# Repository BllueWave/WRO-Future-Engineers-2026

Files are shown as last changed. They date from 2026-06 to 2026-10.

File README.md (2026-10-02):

<p align="center">
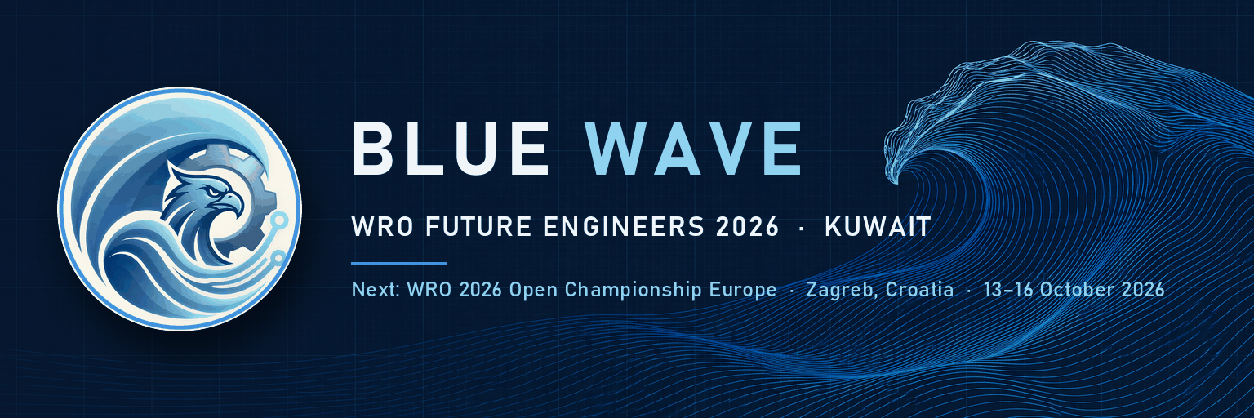
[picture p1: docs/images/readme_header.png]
BLUE WAVE, WRO Future Engineers 2026, Kuwait
  
</p>

<h1 align="center">BLUE WAVE</h1>

<p align="center"><b>WRO Future Engineers 2026 · Kuwait</b><br>Kuwait national round: 1st place, 61 points<br>Next: WRO 2026 Open Championship Europe, Zagreb, Croatia, 13–16 October 2026</p>

<p align="center">
  
  
  
  
  
</p>

Our car is a WLtoys 1:28 four-wheel-drive chassis (one brushed motor, propshaft, front and rear differentials, Ackermann steering) carrying a Raspberry Pi 5, a Hiwonder RRC Lite controller board, an LDROBOT LD19 lidar, an Angstrong HP60C camera and a Cytron MD13S motor driver, inside a body we designed and printed in PETG (BW-2). The car has no wheel encoder. It finds its position from the lidar, which scans 50 mm above the mat so that it sees the 100 mm field walls and the traffic signs, and from the IMU. The camera only tells red from green and finds the magenta parking limitations. All planning and control run in Python on the Pi 5.

Every number on these pages comes from a run log of the car, a calibration file or the CAD model, and the pages say which. **MAT** = measured on the car on our practice mat. **CAD** = read from the body model, not yet measured on the car. **SIM** = our simulator, which is calibrated to the mat but is not the judge.

## Results

| Event or run | Result | Source |
|---|---|---|
| WRO Future Engineers 2026, Kuwait national round, June 2026 | **1st place, 61 points**, won with our first car (Arduino Uno), which stays in the history at tag [`v1.0-june-2026`](https://github.com/BllueWave/WRO-Future-Engineers-2026/tree/v1.0-june-2026) | competition result |
| Open Challenge, practice mat, 2026-10-01 (MAT) | **14.7 s** for 3 laps, 12 of 12 corners driven without stopping, stop inside the start section, no contact, counter-clockwise, pack 8.05 V | run `20261001-161301.412-open_v7`, program `BEST_OPEN_14s` |
| Obstacle Challenge, practice mat, 2026-10-01 (MAT) | **55.8 s**: start in the parking lot, 3 laps with all 6 signs passed on the correct side in every lap, parallel park with all 4 corners inside the lot, counter-clockwise, pack 8.25 V | run `20261001-222840.106-obs_v17`, program `obs_v17` |

All corridors on that mat were 1000 mm wide. Both runs are counter-clockwise; the clockwise runs of these two programs are SIM so far. The full list of mat runs, with the pack voltage of each, is in [Build, test and reproduce](docs/05-build-test-reproduce.md#results-on-the-mat).

## Contents

| Appendix C criterion | Page | What it covers |
|---|---|---|
| 1. Mobility | [Mobility and mechanical design](docs/01-mobility.md) | Why this chassis, size and parking-lot length, drive train and the fitted speed model, braking, steering trim and the unequal steering lock, understeer against speed, the BW-2 body |
| 2. Power and sensors | [Power and sensor architecture](docs/02-power-and-sensors.md) | Power tree and budget, pin map, why a 50 mm lidar plane, camera field of view and pitch, IMU, speed without an encoder, calibration, failure handling |
| 3. Software and obstacle strategy | [Software architecture and obstacle strategy](docs/03-software-and-strategy.md) | Where each module runs, race mode, the Open racing line, the Obstacle pose, sign map and path, the lot exit and the parallel park, constants and their sources |
| 4. Systems thinking and decisions | [Systems thinking and engineering decisions](docs/04-engineering-decisions.md) | Constraints, decision log, the measured lessons (steering trim, battery compensation, the Q stop, the camera's field of view), version history, risks |
| 5. Reproducibility | [Build, test and reproduce](docs/05-build-test-reproduce.md) | Parts list, printed parts, software set-up, race mode, bench check, test method, mat and SIM results, how to repeat each number |

Other folders: [vehicle photos](Vehicle_Photos/README.md) · [wiring](Schemes/README.md) · [3D models](Models/README.md) · [videos](videos/README.md) · [source code](src/README.md) · [test sheet](docs/test-sheet.md)

Scoring reference: section 7 and Appendix C of the [2026 Future Engineers rules](https://wro-association.org/wp-content/uploads/WRO-2026-Future-Engineers-Self-Driving-Cars-General-Rules.pdf).

## The car

<p align="center">
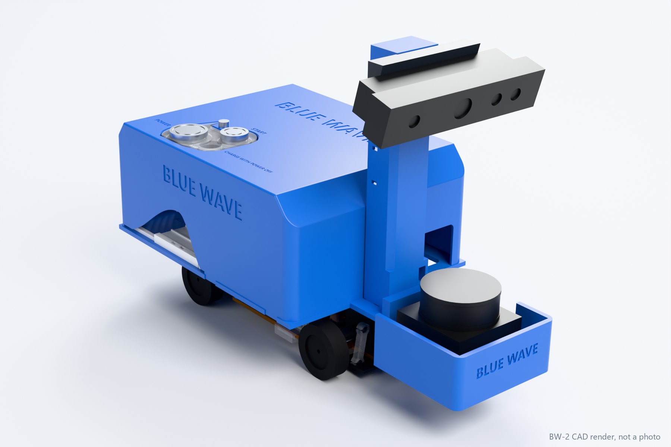
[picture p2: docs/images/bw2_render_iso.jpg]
CAD render of the BW-2 body on the WLtoys chassis: blue shell and tower, camera on the tower, lidar bay at the front
  
  <br><sub>CAD render of the BW-2 model, not a photo. Photos of the car: <a href="Vehicle_Photos/README.md">Vehicle_Photos</a>.</sub>
</p>

| Item | Value | Tag |
|---|---|---|
| Size | 224.8 × 111.0 × 157.2 mm (rule 11.1 limit 300 × 200 × 300 mm) | CAD |
| Mass | 721–737 g estimated from the CAD solids and the part list; this model still includes three printed parts that are not on the car, so the car is lighter; not yet weighed (rule 11.2 limit 1.5 kg) | CAD |
| Chassis | WLtoys 1:28, model 284131: one 130-size brushed motor, propshaft, front and rear differentials, Ackermann front axle; wheelbase 98.0 mm, track 64.24 mm, wheel 27.0 mm | CAD |
| Computer | Raspberry Pi 5 with Active Cooler: perception, planning, control | |
| Controller board | Hiwonder RRC Lite (STM32F407), stock firmware: steering servo pulses, 6-axis IMU at 50 Hz, buzzer, keys; powers the Pi over USB-C | MAT (IMU rate) |
| Drive | Cytron MD13S on Pi GPIO12 (PWM, 490 Hz) and GPIO16 (direction); PWM low = brake | MAT |
| Speed | v = 5.276 m/s × (duty − 0.1012), fitted on 1599 lidar speed samples, rms error 0.075 m/s; 1.39 m/s top speed seen in the 14.7 s run | MAT |
| Steering | stock micro servo on RRC PWM port 3; 30° left and 22° right at the wheels; full-lock left radius 237 mm at 0.2 m/s | MAT |
| Lidar | LDROBOT LD19, 360°, about 10 Hz, scan plane 50 mm above the mat (walls are 100 mm) | CAD (height), MAT (rate) |
| Camera | Angstrong HP60C RGB-D, colour 640 × 480 at 14 frames/s, ±29.3° horizontal field of view, pitch 19.61° down | MAT |
| Power | 7.4 V 2200 mAh pack (2 × 18650), one 16 mm latching power switch | |
| Start | one 12 mm start button on GPIO17 (rules 9.10 and 9.11) | |

<p align="center">
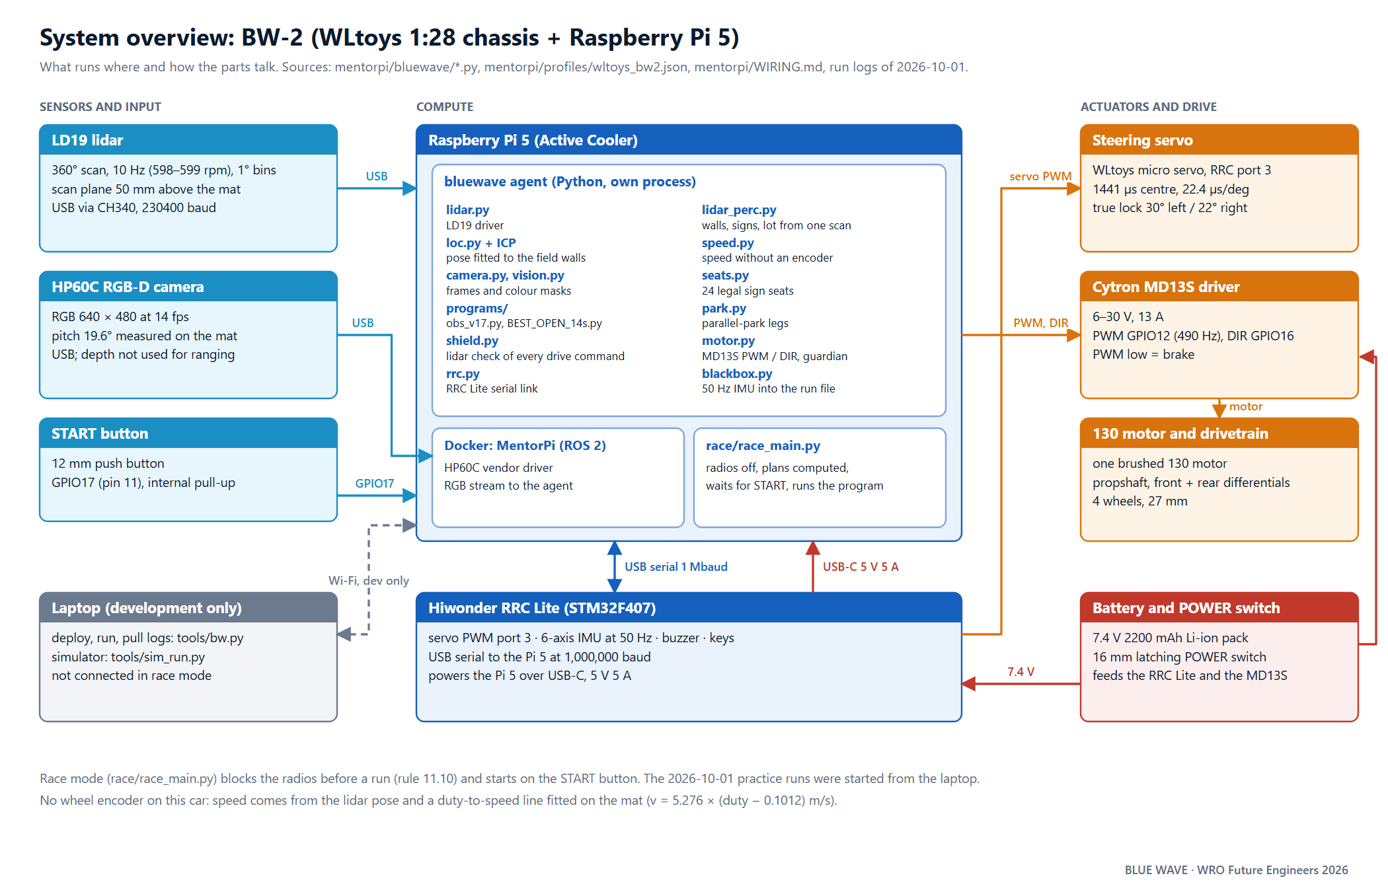
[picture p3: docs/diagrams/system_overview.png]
System overview: the pack feeds the RRC Lite and the MD13S through the power switch; the RRC Lite powers the Raspberry Pi 5 over USB-C and talks to it over USB serial; the LD19 lidar and the HP60C camera are on the Pi's USB ports; the Pi drives the MD13S from GPIO12 and GPIO16; the RRC Lite drives 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
  
</p>

### Why these parts

| Part | Why |
|---|---|
| WLtoys chassis | One drive motor through mechanical differentials and one steering servo, as rules 11.3, 11.5 and 11.13 ask. The robot kit we took the electronics from drives each rear wheel with its own motor, which those rules do not allow. |
| LD19 lidar at 50 mm | On the kit's own mount the lidar scanned above the 100 mm walls and signs and read the room behind the field. At 50 mm every wall and sign within 2.2 m is in the scan, which gives the car an absolute position about ten times a second without an encoder. |
| HP60C colour camera | The lidar finds where a sign stands; the camera only has to say red or green, and where the magenta limitations are. Its depth stream gave no returns from the white mat and over-read a sign at 1.25 m as 1.43 m, so we do not use it for range. |
| Raspberry Pi 5 | Lidar fitting, the colour masks, the path planner and the simulator-compatible robot interface all run in Python at a 40 Hz control loop (p99 loop time 32.0 ms, MAT). |
| Cytron MD13S | The controller board's motor ports close a speed loop on an encoder this car does not have. The MD13S takes plain PWM and direction from the Pi, and PWM low shorts the motor, which brakes at 2.08 m/s² (fit over the mat runs). |

More detail and the trade-offs: [Systems thinking and engineering decisions](docs/04-engineering-decisions.md).

## How it works

### Open Challenge (`BEST_OPEN_14s`)

The lidar scan is rotated by the gyro heading into the corridor frame. From it the car reads the wall ahead, both side walls and the inner corner of the island, which gives the width of the next corridor about 1.3 m before the corner. The driving direction is chosen at the start from the gap at the corner. Every corner is one constant-radius 90° arc from this corridor's lane to the next one's, with the radius as large as a 180 mm clearance to the island allows, and the arc speed √(a·R) with a = 2.6 m/s². Lap 1 measures every corridor; laps 2 and 3 plan each corner from that map before it is in sight. The car brakes to the arc speed with a constant-deceleration plan on a speed observer (the fitted duty line corrected by the lidar), steers each arc with the effective wheelbase measured at that speed, and stops inside the start section after 12 corners. A lidar shield checks every drive command against the walls.

### Obstacle Challenge (`obs_v17`)

```mermaid
flowchart LR
    A["Start in the lot<br>direction from the wall beside the car"] --> B["Lot exit<br>planned legs on the real lock of each side"]
    B --> C["Laps 1 to 3<br>lidar pose, sign seats, lane per sign"]
    C -->|"3 laps done"| D["Ride Q's line<br>stop on the braking distance"]
    D -->|"off Q"| E["Realign: back along the line, in again, creep"]
    E --> D
    D -->|"on Q"| F["Park: the exit plan driven in reverse"]
    F --> G["Check all 4 corners inside the lot"]
```

The pose comes from fitting each lidar scan's wall points to the field walls (outer square, island, the lot's limitations), starting from the gyro and the speed observer. Sign pillars found by the lidar are snapped to the 24 positions the rules allow, and each gets its colour from the camera by bearing. Red is passed on its right, green on its left. A sign the lidar has found but the camera has not read is looked at on purpose: the nose turns toward it, and the program counts pixels where the map projects it into the frame. The path is a lane per sign with planned corner radii, followed by pure pursuit from the rear axle with a swept-footprint guard. After three laps the car rides the line to the point Q where the lot exit ended, stops there, and drives the exit plan in reverse into the lot. The run counts as parked only when all four corners of the car are inside.

Full description, state machines and constants: [Software and strategy](docs/03-software-and-strategy.md).

### Code modules and the parts they use

| Module (in `src/`) | What it does | Parts |
|---|---|---|
| `bluewave/hw.py` | the `Robot` object: one interface on the car and in the simulator | all |
| `bluewave/rrc.py` | serial driver of the RRC Lite (1,000,000 baud): servo pulses, IMU, buzzer, keys | RRC Lite, steering servo, IMU |
| `bluewave/motor.py`, `bluewave/speed.py` | PWM and direction to the MD13S with a stop guardian; speed from the lidar pose and the duty model | MD13S, 130 motor, LD19 |
| `bluewave/lidar.py`, `bluewave/lidar_perc.py` | LD19 driver; walls, pillars and parking limitations from one revolution | LD19 |
| `bluewave/camera.py`, `bluewave/vision.py` | frame grabber and colour masks for red, green and magenta | HP60C |
| `bluewave/field.py`, `bluewave/loc.py` | the field map with the 24 sign seats; localisation | LD19, IMU |
| `bluewave/park.py` | lot exit and parallel park legs on the car's true footprint | all drive parts |
| `bluewave/shield.py` | lidar safety layer that checks every drive command | LD19, MD13S |
| `programs/BEST_OPEN_14s.py` | Open Challenge program | all |
| `programs/obs_v17.py` | Obstacle Challenge program with the parallel park | all |
| `race/race_main.py` | race mode: radios off, READY beeps, waits for the start button, runs the chosen program | start button, buzzer |

## Build and run

1. **Car.** Fit the parts in [Build, test and reproduce](docs/05-build-test-reproduce.md#bill-of-materials) and wire them as in [Schemes](Schemes/README.md). The RRC Lite keeps Hiwonder's firmware; nothing is flashed to it.
2. **Pi 5, once.** On a fresh Raspberry Pi OS Lite (64-bit) card run `src/os/setup_bluewave_os.sh`; it installs `python3-numpy`, `python3-opencv`, `python3-serial` and `python3-lgpio`, the udev rule and the services. On Hiwonder's stock card use `src/os/install_on_stock.sh`, which keeps the vendor container that holds the HP60C driver.
3. **Code.** From the laptop, `py -3 tools/bw.py deploy` (run in `src/`) copies the code to the car. There is nothing to compile: the programs are Python and load at the start of a run.
4. **Calibration file.** `py -3 tools/bw.py body wltoys_bw2` applies the car's numbers from `profiles/wltoys_bw2.json`; the motor and steering fit used by the programs and the simulator is `profiles/plant_mat1001.json`.
5. **Before each round.** Pack at 7.4 V or more, car still: `py -3 tools/bw.py preflight pitch` with one sign 500 mm ahead must answer GO.
6. **Race mode.** Set `race.programs.open=BEST_OPEN_14s`, `race.programs.obstacle=obs_v17` and `race.challenge` for the round, then `py -3 tools/bw.py mode race` and power-cycle the car. At boot every radio is blocked before the race program starts (rule 11.10); two beeps mean READY; the car does not move before the start button.

Step-by-step commands, the bench check and the simulator: [Build, test and reproduce](docs/05-build-test-reproduce.md) and [src/README.md](src/README.md).

## Rules the car must meet

| Rule | Requirement | This car |
|---|---|---|
| 11.1 | at most 300 × 200 × 300 mm | 224.8 × 111.0 × 157.2 mm (CAD); the car keeps one shape at the start, in the lot exit and in the park |
| 11.2 | at most 1.5 kg | 721–737 g (CAD estimate that includes three printed parts not on the car; not yet weighed) |
| 11.3 | four wheels, one driving axle, one steering actuator | one motor through a propshaft and two differentials; one steering servo |
| 11.5, 11.13 | drive motors may not be connected to wheels independently | one drive motor |
| 11.10 | no wireless communication during a round | race mode runs `rfkill block all` before the program starts |
| 9.10 | one power switch | one 16 mm latching switch on the pack's positive lead |
| 9.11 | one start button, the car waits for it | `race_main.py` waits for the one start button before the car moves |

## Repository map

```text
.
├── README.md            this page
├── docs/                criterion pages 01 to 05, test sheet
│   ├── diagrams/        system, wiring, power, sensors, dimensions, run traces
│   ├── images/          header, CAD renders, team cards
│   ├── arena/           3D model of the 2026 field
│   └── team_photos/     work sessions
├── src/                 the code that runs on the Pi 5 (see src/README.md)
├── Models/              printed parts of the BW-2 body (STL)
├── Schemes/             wiring schematic and pin table
├── Vehicle_Photos/      six views of the car
└── videos/              challenge videos
```

| WRO template folder | This repository |
|---|---|
| `t-photos` | `docs/team_photos/` |
| `v-photos` | `Vehicle_Photos/` |
| `video` | `videos/` |
| `schemes` | `Schemes/` |
| `src` | `src/` |
| `models` | `Models/` |
| `other` | `docs/` |

## Team

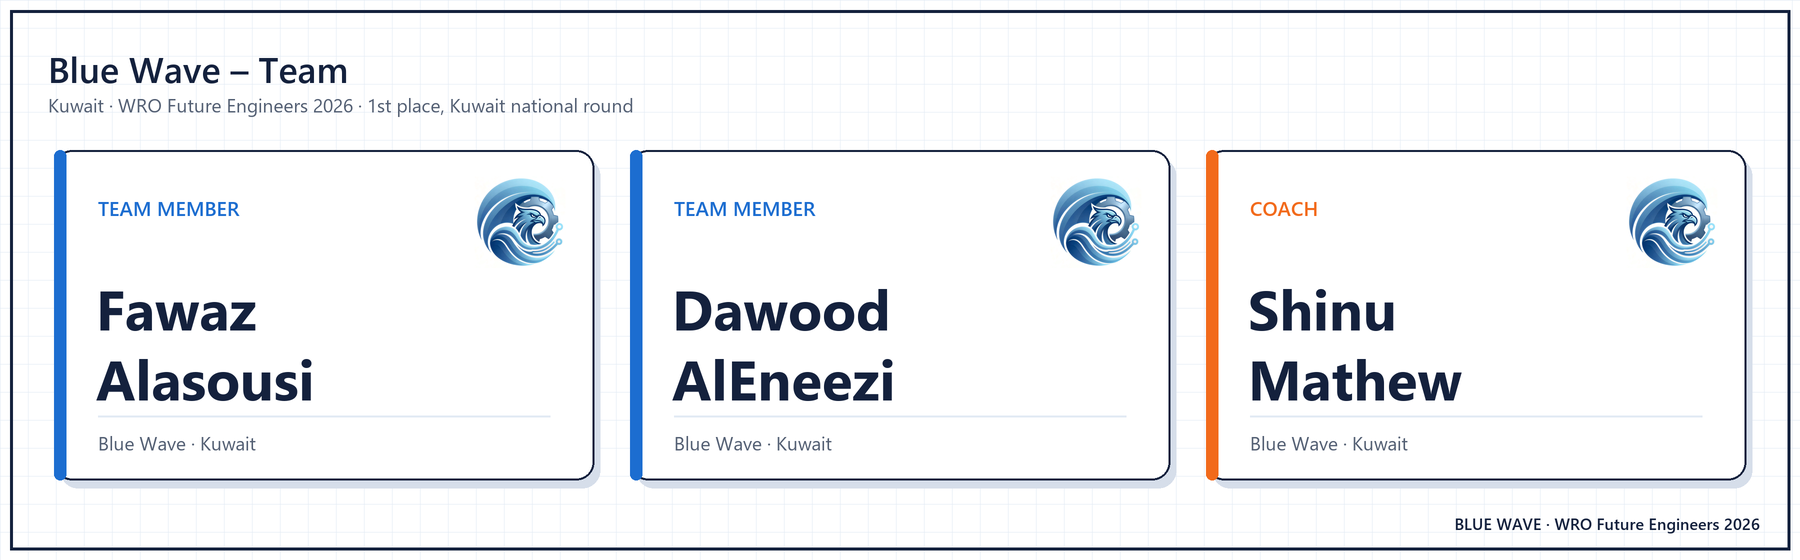
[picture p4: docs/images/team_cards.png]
BLUE WAVE team: Fawaz Alasousi and Dawood AlEneezi, team members; Shinu Mathew, coach


<p align="center">
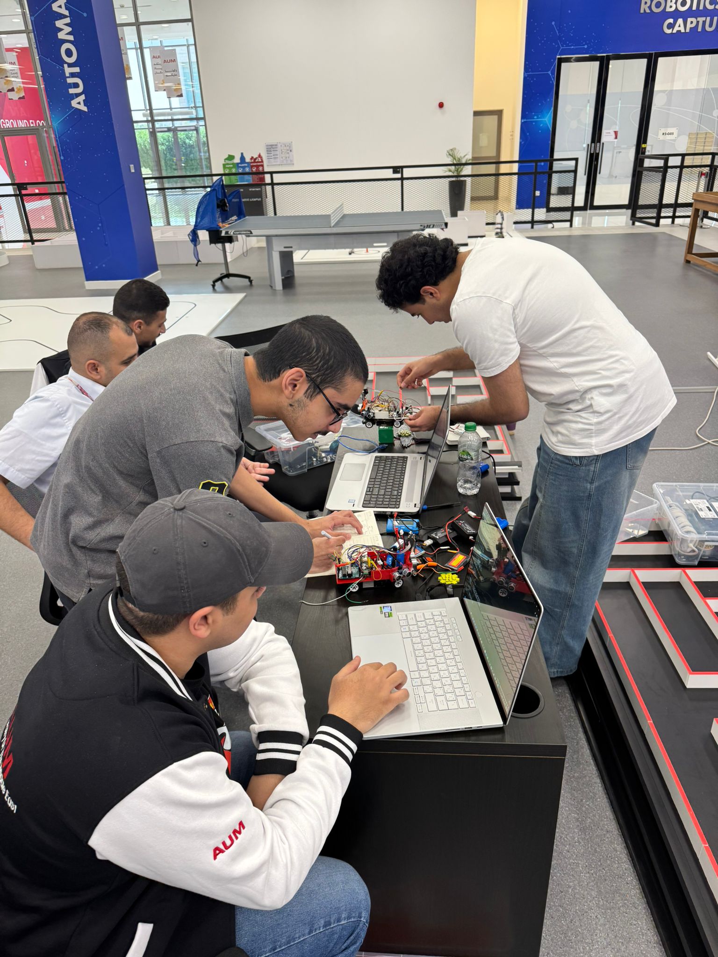
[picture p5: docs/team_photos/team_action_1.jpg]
Work session: the car on the table with laptops
  
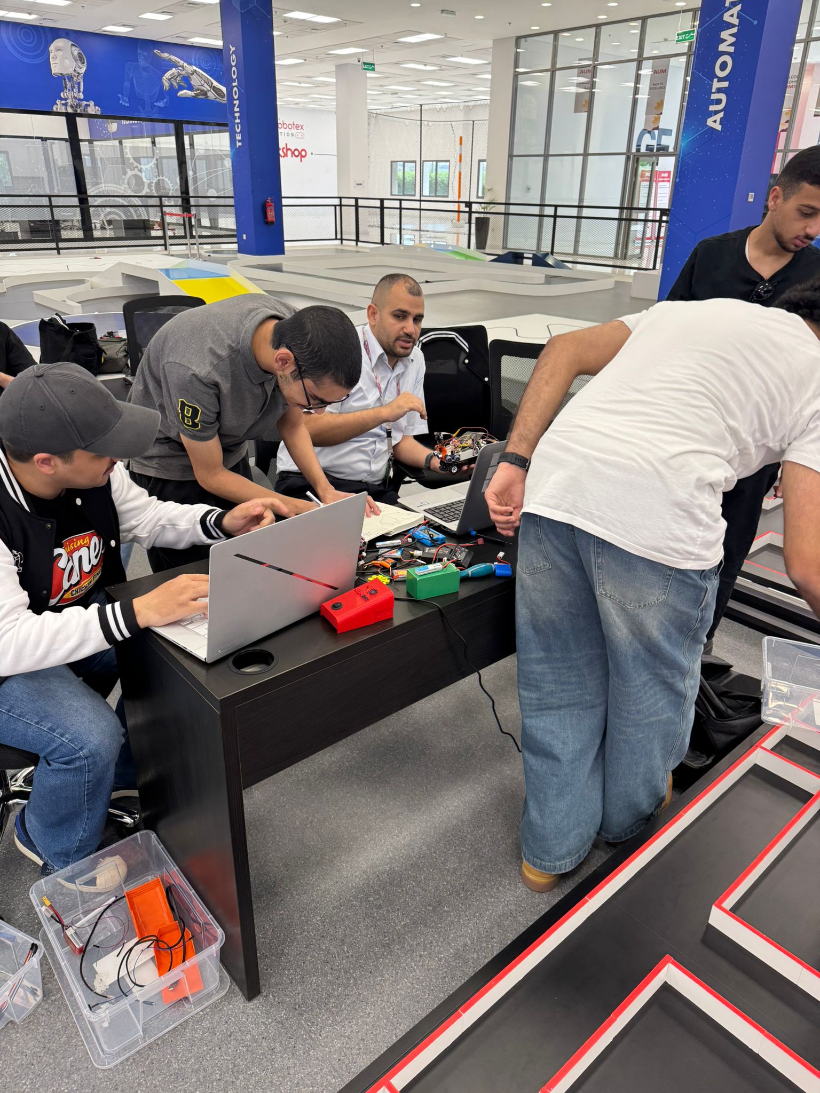
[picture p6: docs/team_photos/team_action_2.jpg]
Work session: testing the car at the field
  
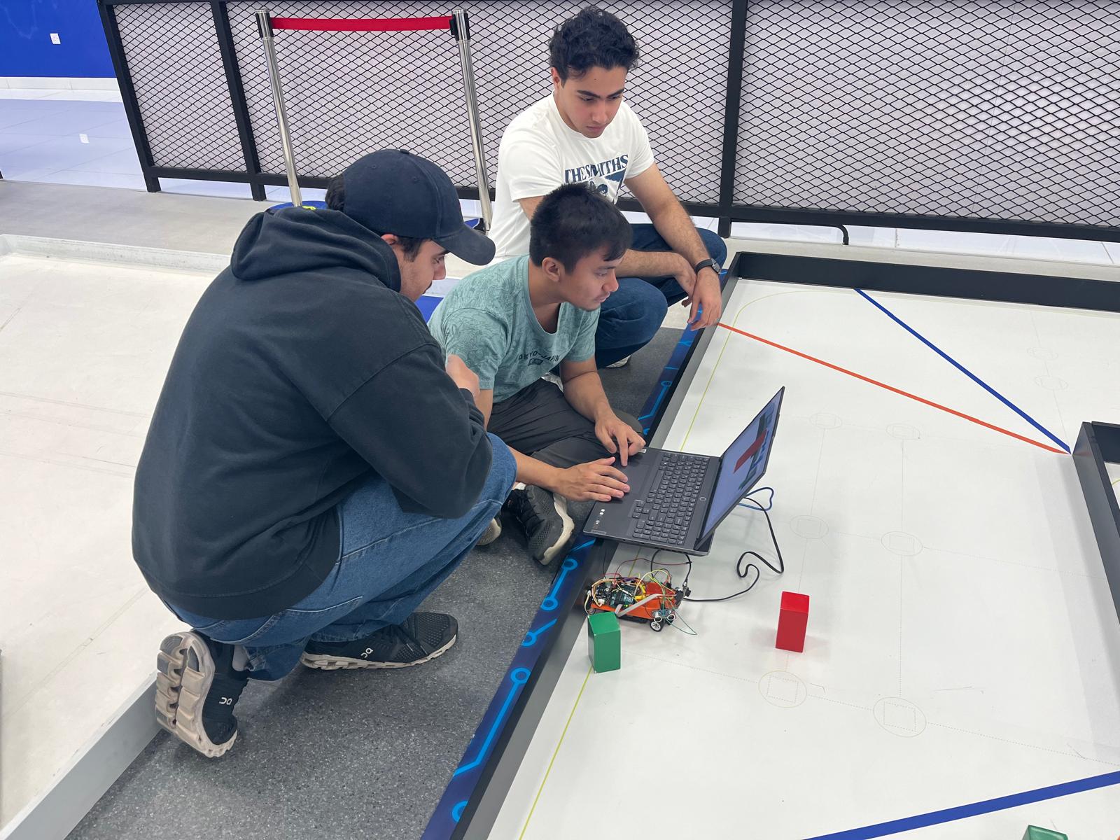
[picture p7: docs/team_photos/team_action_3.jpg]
Work session: tuning the car on the mat
  
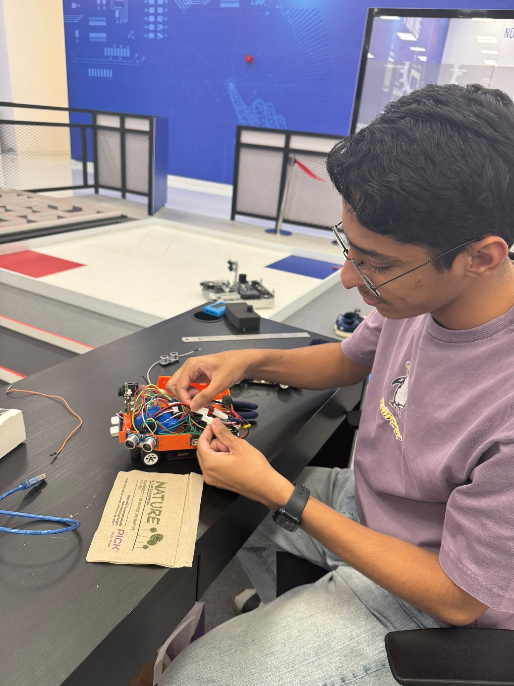
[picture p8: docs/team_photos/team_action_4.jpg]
Work session: wiring the car at the bench
  
</p>

<p align="center"><sub>BLUE WAVE · Kuwait · WRO Future Engineers 2026</sub></p>

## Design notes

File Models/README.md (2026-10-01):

# 3D models: the BW-2 body

The body of our car is BW-2, designed by the team for the WLtoys 1:28 chassis and the MentorPi electronics, and printed
in PETG. Five printed parts are on the car. GitHub shows each STL file in a 3D viewer when you open it.

<p align="center">
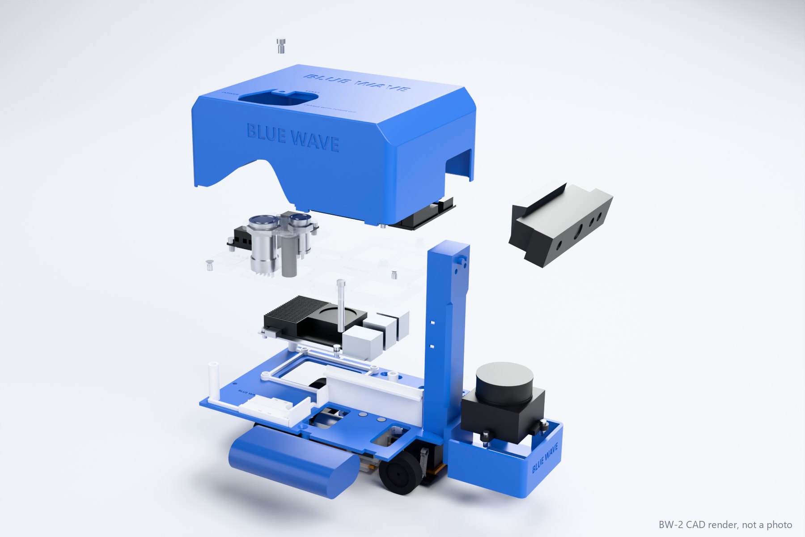
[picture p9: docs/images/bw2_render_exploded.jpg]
Exploded CAD render of the BW-2 body: deck, frame and battery tray, tower with the lidar bay and camera mast, 16 degree camera wedge, shell
  
  <br><sub>CAD render, not a photo.</sub>
</p>

## Printed parts on the car

Material PETG, 0.4 mm nozzle. Print times and masses are slicer estimates. The colour is the one we printed; the file
names keep the colour of the CAD model so that they still match the SHA-256 hashes we recorded for each printed file.

| File | Part | Printed colour | Layer / walls / infill | Supports | Time | Mass |
|---|---|---|---|---|---|---|
| `01_D1_deck_darkgrey.stl` | deck that mounts on the chassis; unchanged from our first body version | blue | | | | 40.9 g |
| `02_L1_frame_battery_tray_darkgrey.stl` | frame and battery tray, with the Pi 5 bosses and the battery bay | white | 0.2 mm / 4 / 40 % | none | 42 min | 14.0 g |
| `04_tower_blue.stl` | tower: camera mast and lidar bay in one print, with 4 lapped datum pads | blue | 0.2 mm / 4 / 40 %, 5 mm brim | enforcer under the foot; blockers in the bores and the cable channel | 115 min | 33.3 g |
| `05_shell_blue.stl` | shell: one print, flat roof, 1.2 mm skin | blue | 0.2 mm / 3 lines of 0.40 mm / 15 % | none | 164 min | 60.6 g |
| `07_cam_wedge_16deg_darkgrey.stl` | camera wedge, 16° | dark grey | 0.12 mm / 5 / 50 % | none | 32 min | 7.9 g |

Total: 157 g of PETG; 353 min of printing for parts 02, 04, 05 and 07.

## What the parts set

| Feature | Value | Set by |
|---|---|---|
| Lidar scan plane | 50.0 mm above the mat, below the top of the 100 mm walls | tower (lidar bay) |
| Lidar position | centre line, 152.0 mm ahead of the rear axle | tower |
| Camera lens | 149.4 mm ahead of the rear axle, 138.28 mm above the mat | tower (mast) |
| Camera pitch | 16° in the model; 19.61° measured on the car | wedge on the mast |
| Overall size | 224.8 × 111.0 × 157.2 mm | whole body |

All values are from the CAD model except the measured pitch. Why these positions: [Mobility](../docs/01-mobility.md#the-bw-2-body)
and [Power and sensors](../docs/02-power-and-sensors.md#sensors).

## Design checks

Run on the full CAD assembly on 2026-09-25 before printing:

| Check | Result |
|---|---|
| Clearance between parts | 91 part pairs, no violation; tightest gap 0.35 mm |
| Contacts | 93 contacts, no part floating |
| Print files | every file a closed single solid |
| Camera view | clear of the body by 22.1 mm |
| Cable routes | 18 of 18 clear |
| Screw access | every screw head reachable in build order |
| Size rule 11.1 | 224.8 × 111.0 × 157.2 mm against 300 × 200 × 300 mm |

## Rule we keep for printed files

A file that has been printed is never edited. A changed part is a new file with a new name, printed and recorded
again. This keeps every printed part traceable to the exact file it came from.

<sub>[Back to the README](../README.md)</sub>

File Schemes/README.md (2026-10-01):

# Wiring

<p align="center">
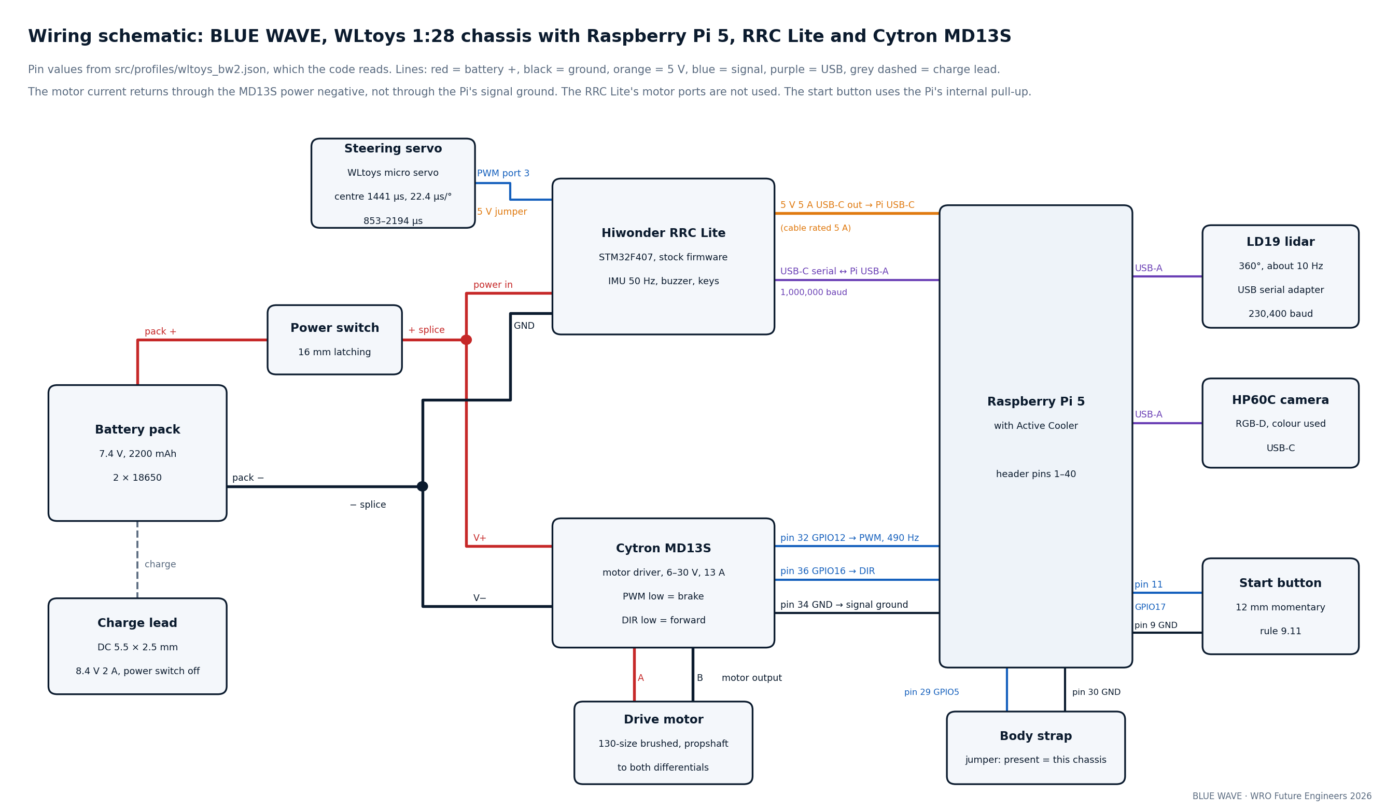
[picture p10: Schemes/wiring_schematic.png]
Wiring schematic: 7.4 V pack, 16 mm power switch, positive and negative splices to the RRC Lite and the Cytron MD13S; RRC Lite 5 V USB-C to the Raspberry Pi 5; Pi GPIO12 and GPIO16 to the MD13S PWM and DIR; MD13S to the drive motor; RRC Lite PWM port 3 to the steering servo; start button on GPIO17;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
  
</p>

Every electrical connection of the car: power, signal and ground, between the battery, the power switch, the RRC Lite
board, the Raspberry Pi 5, the Cytron MD13S motor driver, the drive motor, the steering servo, the LD19 lidar, the
HP60C camera, the start button and the body strap. The pin values are the ones in the car's calibration file
`src/profiles/wltoys_bw2.json`, which the code reads.

The drawing's source is [`wiring_schematic.svg`](wiring_schematic.svg). Other views of the same wiring: [pin map](../docs/diagrams/wiring_pinmap.png), [power tree](../docs/diagrams/power_tree.png),
[system overview](../docs/diagrams/system_overview.png).

## Power

| From | To | Notes |
|---|---|---|
| Pack + (7.4 V, 2200 mAh) | 16 mm latching power switch | the only power switch (rule 9.10) |
| Power switch | positive splice → RRC Lite power input and MD13S V+ | |
| Pack − | negative splice → RRC Lite ground and MD13S V− | one negative point for both |
| RRC Lite 5 V 5 A USB-C output | Raspberry Pi 5 USB-C | use a cable rated 5 A: a 3 A cable cut the Pi's USB ports to 0.6 A |
| Pi 5 USB-A | LD19 (through its USB serial adapter), HP60C | powered by the Pi |
| Charge lead (DC 5.5 × 2.5 mm) | pack | charge at 8.4 V 2 A with the power switch off |

The motor current returns through the MD13S power negative, not through the Pi's signal ground. Do not unplug the MD13S
negative alone while the signal cable is connected.

## Signals

Pin numbers are the Raspberry Pi 5 header pins (1–40).

| Component | Connection | Setting in the calibration file |
|---|---|---|
| Cytron MD13S PWM | Pi pin 32, GPIO12 | 490 Hz software PWM |
| Cytron MD13S DIR | Pi pin 36, GPIO16 | low = forward |
| Cytron MD13S signal ground | Pi pin 34 | |
| Drive motor | MD13S motor output | PWM low = brake |
| Start button (12 mm, momentary) | Pi pin 11, GPIO17, and pin 9, GND | internal pull-up; press and release |
| Body strap (jumper) | Pi pin 29, GPIO5, and pin 30, GND | present = this chassis |
| Steering servo | RRC Lite PWM port 3, supply jumper at 5 V | centre 1441 µs, 22.4 µs per degree, 853–2194 µs |
| RRC Lite | Pi USB-A to the board's USB-C serial port | 1,000,000 baud |
| LD19 lidar | Pi USB-A through the lidar's USB serial adapter | 230,400 baud |
| HP60C camera | Pi USB-A to the camera's USB-C | |

## Wiring rules we keep

- Every stop in the code sets the PWM to zero and then drives DIR low.
- The servo port's supply jumper must be at 5 V; measure 4.8–5.2 V before plugging the servo.
- The RRC Lite's motor ports are not used: they expect a motor with an encoder.

<sub>[Back to the README](../README.md)</sub>

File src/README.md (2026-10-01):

# Source code

This folder is the software of our car: a WLtoys 1:28 chassis (284131) carrying a Raspberry Pi 5, a Hiwonder RRC Lite
board (steering servo, IMU, buzzer), an LDROBOT LD19 lidar, an Angstrong HP60C RGB-D camera and a Cytron MD13S motor
driver. Everything is Python 3. It runs on the Pi 5; the laptop tools deploy it, start runs, pull the run logs back and
run the same program files in a simulator.

The tree is the code as deployed for our practice-mat session of 1 October 2026, the session in which both competition
programs below set their times. One default differs from that deployment: race mode's default programs
(`race.programs` in `bluewave/params.py`) now name the two programs below. The Arduino code of our previous car stays
in the git history of this repository.

The design reasoning is in [docs/03-software-and-strategy.md](../docs/03-software-and-strategy.md); the test method and
results are in [docs/05-build-test-reproduce.md](../docs/05-build-test-reproduce.md).

## Layout

```
src/
  programs/            the competition programs, one file each, loaded by name
    BEST_OPEN_14s.py     Open Challenge
    obs_v17.py           Obstacle Challenge
    _library.json        the console's program list: rank, status and the team's mat notes (Arabic)
  bluewave/            the robot package: drivers, perception, localisation, safety, run logs, simulator, console
  race/race_main.py    race mode: radios off, one START button, then the program
  profiles/            wltoys_bw2.json = this car's calibration; plant_mat1001.json = the simulator's mat-fitted plant
  tools/               laptop side: bw (deploy, run, test, pull), sim_run, fit_plant, lib_push
  os/                  Raspberry Pi setup: systemd services, udev rule, sudo rules
  requirements.txt     laptop packages
  requirements-robot.txt  Pi packages
```

| folder | files | lines |
|---|---|---|
| `bluewave/` | 43 Python files + `ui/index.html` (the web console) | 20,772 Python |
| `programs/` | 2 programs + the library seed | 1,998 + 1,945 |
| `race/` | `race_main.py` | 128 |
| `tools/` | 11 Python files | 4,296 |
| `os/` | 10 files | 306 |

`src/` has the same layout as the `mentorpi/` folder of our robot repository, so the commands below and the relative
paths the tools use resolve from `src/`. Some code comments name design notes of the robot repository (`docs/*_SPEC.md`,
`plans/*.json`, `3d/...`) that are not part of this tree.

### The `bluewave` package

| module | what it does |
|---|---|
| `hw.py` | `Robot`: the one object a program drives. The simulator builds the same object, so a program file runs unchanged on the car and on the laptop. |
| `rrc.py` | RRC Lite serial driver at 1,000,000 baud: servo pulses, IMU stream, buzzer, keys. |
| `motor.py` | MD13S drive: PWM on GPIO12, DIR on GPIO16, software PWM through `lgpio`. A separate guardian process zeroes the PWM if the program process dies. |
| `speed.py` | Speed without a wheel encoder: the lidar pose plus a duty-to-speed line fitted on the mat. |
| `lidar.py`, `lidar_perc.py` | LD19 driver; walls, pillars and parking limitations from one revolution. |
| `loc.py`, `globloc.py` | Particle filter; whole-field position search from still views. |
| `field.py`, `seats.py` | The field map with the 24 legal sign positions; each sign's position from the lidar and its colour from the camera. |
| `camera.py`, `vision.py` | Frame grabber (the HP60C colour stream) and the colour masks. |
| `park.py` | Parallel-parking legs planned on the car's true footprint. |
| `shield.py` | Lidar safety layer: every drive command is checked against the free space before it reaches the motor. |
| `blackbox.py`, `runlog.py` | 50 Hz IMU record and the run file (one JSON line per event or telemetry sample). |
| `analyze.py`, `report_html.py` | After a run: where and why the car touched something, as text and as an HTML report. |
| `params.py`, `paramstore.py`, `progmeta.py` | Robot parameters with defaults, history and undo; profiles; program metadata and presets. |
| `mock.py` | The simulator: lidar, camera image, IMU and drive with the same interfaces as the hardware. |
| `tests.py`, `tests_cal.py` | Component and calibration tests run from the console or `bw test` (duty sweep, coast, turn radius, camera pitch, lidar tilt, field check). |
| `agent.py`, `hub.py`, `*_api.py`, `ui/` | Development server (FastAPI, port 8000) and the web console. Used in dev mode only. |
| `depth_bridge.py`, `ros_bridge.py` | Run inside Hiwonder's ROS 2 container: the HP60C depth stream, and read-only ROS topics for Foxglove or RViz. |

## The competition programs

Best runs on our practice mat, 1 October 2026 (all four corridors 1000 mm). Times are the program's own clock.

| challenge | file | result | direction | pack at start | run |
|---|---|---|---|---|---|
| Open | `programs/BEST_OPEN_14s.py` | 3 laps in 14.7 s, 12/12 corners, stopped inside the start section, no contact | counter-clockwise | 8.05 V | `20261001-161301.412-open_v7` |
| Obstacle | `programs/obs_v17.py` | 3 laps and a parallel park in 55.8 s, all four car corners inside the lot | counter-clockwise | 8.25 V | `20261001-222840.106-obs_v17` |

`BEST_OPEN_14s.py` is `open_v7` with its preset `l2` (planned lateral acceleration 2.6 m/s^2, speed cap 1.8 m/s) made
the defaults; the mat run was filed under `open_v7`. Neither program has been run clockwise on the mat yet.

**Open, `BEST_OPEN_14s.py`.** The lidar scan is rotated into the corridor frame by the gyro yaw. Each corner is one
constant-radius 90-degree arc from lane to lane, as wide as the inner wall allows, driven at
sqrt(planned lateral acceleration x radius). Lap 1 measures every corridor's width; laps 2 and 3 plan each corner from
that map before it is in sight. The speed comes from the mat-fitted duty line, corrected by the change of the front-wall
distance; braking to the arc speed follows a constant-deceleration plan (1.8 m/s^2). The car stops inside the start
section on the planned front-wall distance.

**Obstacle, `obs_v17.py`.** Pose: every scan's wall points are fitted to the known field walls (point-to-line ICP,
seeded by the gyro and the speed). Signs: lidar pillar clusters are snapped to the 24 legal positions and coloured by the
camera, matched by bearing, so the camera pitch does not enter the colour decision; red is passed on its right, green
on its left. Path: one lane per sign, checked against signs, inner wall and lot, followed by pure pursuit from the rear
axle. The lot exit and the park are planned on the measured steering lock of each side (30 degrees left, 22 degrees
right). The park starts with a braked stop at a fixed point beside the lot and is counted as parked only when all four
corners are inside. The program does not implement a direction change after the second lap.

### The program contract

Each program is one file with a `DEFAULTS` dict, optional `PRESETS`, and

```python
def run(robot, params, log, stop, hook=None): ...
```

- `robot` is `bluewave.hw.Robot` (on the car or in the simulator).
- `params` is layered: `DEFAULTS` < the chosen preset < the robot's per-program parameters < the run's own `k=v`.
- `log(dict)` writes one JSON event to the run file.
- `stop` is a `threading.Event`; the program returns when it is set.

The run file lands in `runs/<time>-<program>.jsonl` on the robot, with the parameters and robot parameters in its first
line, so a run can be traced to the exact numbers it ran on.

## Car interface

Values from `profiles/wltoys_bw2.json`; the full harness is in [Schemes/](../Schemes/).

| signal | Pi 5 header pin | GPIO / port | note |
|---|---|---|---|
| motor PWM | 32 | GPIO12 | 490 Hz software PWM (`drive.pwm.hw_pwm` 0) |
| motor DIR | 36 | GPIO16 | DIR low = forward (`drive.pwm.dir_forward_high` false) |
| START button | 11, GND 9 | GPIO17 | internal pull-up; read as the RRC's KEY1 |
| body strap | 29, GND 30 | GPIO5 | jumper present = this chassis (`bodyid.py`) |
| steering servo | - | RRC Lite PWM port 3 | centre 1441 us, 22.4 us per degree |
| RRC Lite | USB | `/dev/rrc` | udev rule in `os/99-bluewave.rules` |

Drive safety in the profile: PWM-low brake on every stop, a 200 ms command watchdog (`drive.pwm.watchdog_ms`), motor cut
after 0.8 s of stall (`drive.stall_s`).

## Running on the robot

The commands run on the laptop from `src/`, in Git Bash or cmd (PowerShell rejects the `<` redirections used in
`os/`). The robot address and the optional console token come from the environment, never from a file in this tree:

| variable | default | meaning |
|---|---|---|
| `BW_HOST` | `bluewave.local` | robot address |
| `BW_PORT` | `8000` | dev server port |
| `BW_USER` | `bluewave` | SSH user (key login; `bw.py` uses `~/.ssh/bluewave_ed25519` when it exists) |
| `BW_TOKEN` | empty | console token, if the robot sets one |

1. **Set up the Pi once.** On a fresh Raspberry Pi OS Lite (64-bit) card: `os/setup_bluewave_os.sh` (installs the
   packages, the udev rule, the dev and race services). On Hiwonder's stock card: `os/install_on_stock.sh` (keeps
   Hiwonder's container for the HP60C driver and adds the dev server).
2. **Deploy:** `py -3 tools/bw.py deploy` copies `bluewave/`, `programs/`, `race/` and `profiles/` to the robot and
   restarts the dev server. It refuses while a program drives the car.
3. **Select the car's profile:** `py -3 tools/bw.py body wltoys_bw2` (applies the profile, checks the body strap and the
   lidar fingerprint, restarts the server).
4. **Calibrate with the car still:** `py -3 tools/bw.py preflight pitch` with one pillar 500 mm ahead of the bumper,
   then `py -3 tools/bw.py preflight` until every row says GO (battery, board, gyro bias, camera, lidar, body).
   The camera pitch is measured on the car, not taken from the CAD: the profile carries the 16-degree wedge angle, the
   car ran on 19.61 degrees measured on 1 October 2026.
5. **Run:** `py -3 tools/bw.py run BEST_OPEN_14s --wait-button` or `py -3 tools/bw.py run obs_v17 --wait-button`; the car
   waits for its START button. Ctrl-C stops it.
6. **Read the run back:** `py -3 tools/bw.py runs`, `py -3 tools/bw.py pull RUN_ID`,
   `py -3 tools/bw.py analyze latest`.

`py -3 tools/bw.py help` lists the other commands (live telemetry, component tests, parameters, presets, logs).

### Race mode

Rule 11.10 wants every radio off during a run, and rules 9.10 and 9.11 allow one power switch and one start button.
Race mode is that path, on the card set up by `os/setup_bluewave_os.sh`:

1. Choose the programs and the challenge:
   `py -3 tools/bw.py apply race.program= race.programs.open=BEST_OPEN_14s race.programs.obstacle=obs_v17 race.challenge=open`
   (`race.challenge=obstacle` for the Obstacle round).
2. `py -3 tools/bw.py mode race`, then power-cycle the car.
3. At boot `os/bluewave-mode.sh` blocks every radio (`rfkill block all`) and starts `race/race_main.py`. It loads the
   program and computes what can be computed before the car moves, beeps twice (READY), and waits for START. Then it
   runs the program and writes `runs/<time>-race-<program>.jsonl`.
4. Holding the second RRC key long returns to dev mode (radios on, dev server started).

## Running in the simulator

```sh
py -3 -m pip install -r requirements.txt
py -3 tools/sim_run.py BEST_OPEN_14s --profile wltoys_bw2 --mat1001 --open --corridors 1000,1000,1000,1000 --seed 5
py -3 tools/sim_run.py obs_v17 --profile wltoys_bw2 --mat1001 --lot --lot-start --seed 2
```

- `--profile wltoys_bw2` builds the simulated car from this car's profile (body, sensors, steering limits).
- `--mat1001` replaces the simulator's drive and steering with `profiles/plant_mat1001.json`, fitted by
  `tools/fit_plant.py` to 20 mat run logs of 30 September and 1 October 2026: speed = 5.276 m/s per unit duty x
  (duty - 0.1012), rms error 0.075 m/s over 1,599 lidar speed samples; PWM-low brake 2.08 m/s^2; speed lag 0.56 s;
  steering bias +4.05 degrees; effective wheelbase 137 mm at 0.2 m/s rising to 280.7 mm at 1.7 m/s (2,694 corner
  samples). The car understeers more as it goes faster, and the fitted curve is what the simulated car steers with.
- `--open` draws 600 / 1000 mm corridors from the seed (`--corridors S,E,N,W` fixes them); `--lot --lot-start` places
  the parking lot and starts the car in it; `--cw` runs clockwise; `--seeds 1-8` runs a batch, one line each;
  `--runfile DIR` writes a run file the analyzer reads; `--fault '{...}'` injects a fault mid-run (camera pitch jump, lidar dropout, battery sag, frozen camera, stuck wall
  reading).
- Each run prints the program's events, one JSON line each, then a `RESULT` line: reason, laps, seconds, contacts,
  wrong-side passes, park corners inside, maximum lateral acceleration.

The simulator finds bugs and regressions before the mat. It does not prove a program: a result counts when the car
repeats it on the mat.

## Configuration and secrets

No network name, password, key or token is stored in this tree. The robot address, SSH user and console token come
from the environment variables above or from an untracked `.robot.json` beside `tools/` (listed in `.gitignore`). SSH
uses key login only.

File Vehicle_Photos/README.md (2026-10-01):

# Vehicle photos

Section 7 of the 2026 rules asks for photos of the car from every side, from the top and from the bottom. This page
holds the six photos of the car as it races: WLtoys chassis, BW-2 body, LD19 lidar and HP60C camera fitted.

The photos are being taken. Until each file is added, its cell below says so; we do not put a CAD render in place of a
photo. The CAD renders of the body are on the [Models](../Models/README.md) page, marked as renders.

| View | File | What it should show | Status |
|---|---|---|---|
| Front | `front.jpg` | camera on the tower, lidar bay, nose | photo to be added |
| Back | `back.jpg` | rear of the shell and the chassis | photo to be added |
| Left | `left.jpg` | full left side: shell, tower, camera mast, wheels | photo to be added |
| Right | `right.jpg` | full right side: shell, tower, camera mast, wheels | photo to be added |
| Top | `top.jpg` | roof of the shell, tower and camera from above | photo to be added |
| Bottom | `bottom.jpg` | underside of the chassis: motor, propshaft, steering linkage | photo to be added |

How we take them: the car on a plain background, the camera level with the car's centre for the four sides, straight
down for the top, the car on its roof for the bottom, the same light for all six, cropped to the car.

<sub>[Back to the README](../README.md)</sub>

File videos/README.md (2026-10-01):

# Videos

Section 7 of the 2026 rules asks for one YouTube video per challenge, public or unlisted, in which the part showing
autonomous driving lasts at least 30 s.

## Challenge videos

| Challenge | YouTube | Program | Autonomous driving in the video |
|---|---|---|---|
| Open Challenge | link to be added | `BEST_OPEN_14s` | at least two full runs (one run is 14.7 s on our mat) |
| Obstacle Challenge | link to be added | `obs_v17` | one full run with the park (55.8 s on our mat) |

## How we film a challenge video

| Challenge | What the video shows |
|---|---|
| Open Challenge | the car still in the start section; the start button; three laps; the stop inside the start section. Then a second full run, so the autonomous part is longer than 30 s. |
| Obstacle Challenge | the car parked in the lot; the start button; the lot exit; three laps with every sign passed on its correct side; the parallel park with all four corners inside. |

Both videos are filmed in race mode: radios off, the program started only by the start button. One continuous shot
per run, no cuts during driving. The video description names the program file and the pack voltage at the start.

Each link goes in the table above and in the [Results](../README.md#results) section of the main README.

<sub>[Back to the README](../README.md)</sub>

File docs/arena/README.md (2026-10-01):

# 3D arena model (WRO 2026 rulebook dimensions)

`index.html` in this folder is an interactive three.js model of the WRO 2026 Future Engineers field. We use it to look at a legal random draw from any angle before we test a strategy on the mat, and to check how our 224.8 × 111.0 mm car (BW-2, from CAD) fits the start zone and its 337.2 mm parking lot. It draws the field. It does not simulate driving and it does not score a run.

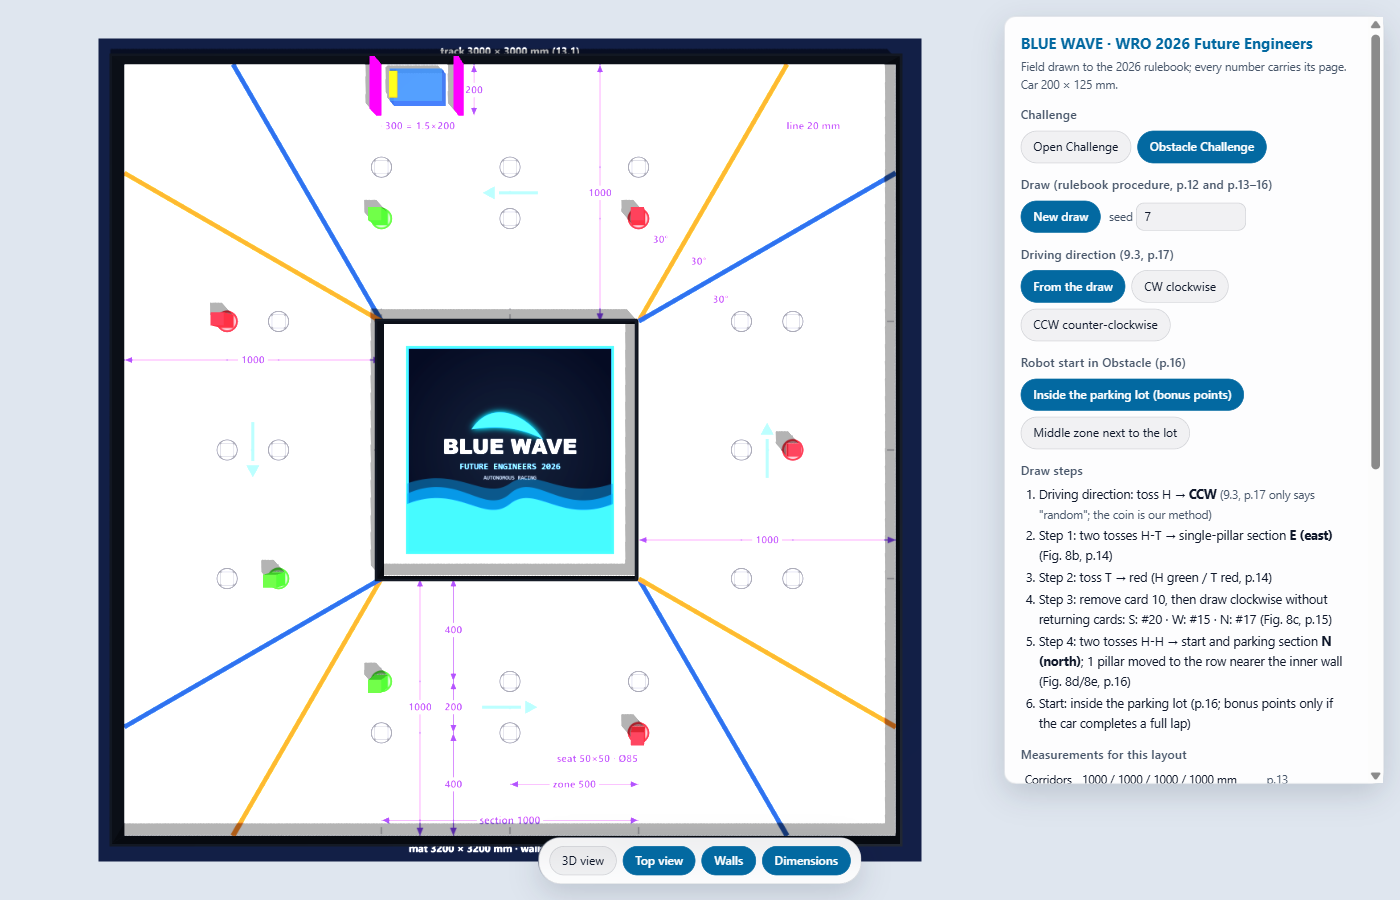
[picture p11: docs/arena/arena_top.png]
Top view of the arena page: an Obstacle Challenge draw with seven pillars, the parking lot in the north straight and the control panel on the right


*Top view of an Obstacle Challenge draw, seed 7: counter-clockwise, parking lot in the north straight, 4 red and 3 green pillars. To rebuild it, choose Obstacle Challenge, type 7 in the seed box and press Top view.*

## SIM replay of the Obstacle program on our practice-mat layout

`obs_v17_replay.html` replays our Obstacle Challenge program `obs_v17` on the layout of our practice mat of 1 October 2026: six traffic signs, the parking lot in the start straight, counter-clockwise, all corridors 1000 mm. It is a single self-contained file (no internet needed). Press Play, or drag the time slider.

It draws two runs of the same program on the same field:

- **SIM** (blue line): the true pose in our simulator (`tools/sim_run.py` with the car model fitted to 20 practice-mat run logs of 30 September and 1 October), seed 1.
- **MAT** (orange dashed line): run `20261001-222840.106` on the real mat, pack at 8.25 V. This is the robot's own pose estimate (lidar scan fitted to the field walls, logged twice a second). We had no external tracking, so it is not ground truth.

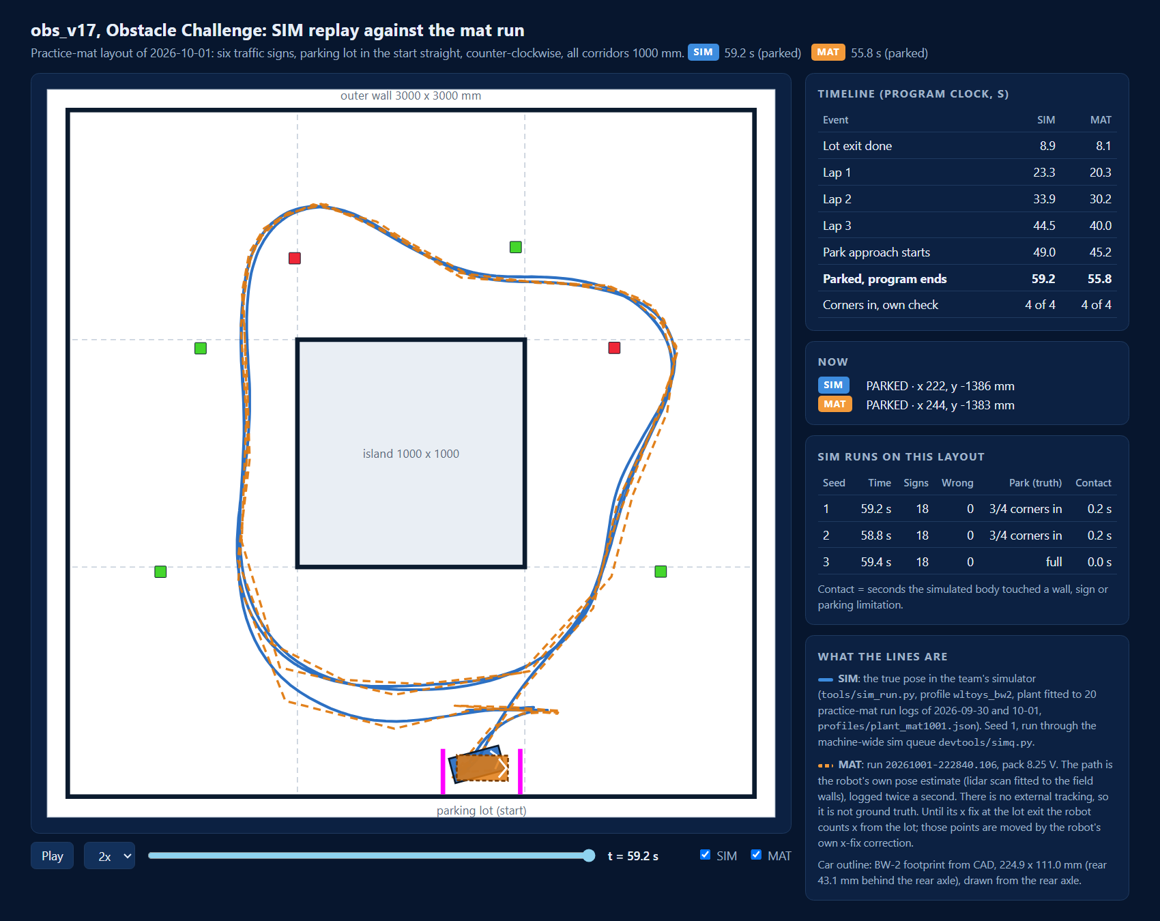
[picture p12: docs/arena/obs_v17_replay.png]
Top view of the practice-mat layout with six signs and the parking lot, the SIM path in blue and the mat path in orange, and a timeline table comparing the two runs


| Event (program clock) | SIM seed 1 | MAT |
|---|---|---|
| Lot exit done | 8.9 s | 8.1 s |
| Lap 1 / 2 / 3 | 23.3 / 33.9 / 44.5 s | 20.3 / 30.2 / 40.0 s |
| Park approach starts | 49.0 s | 45.2 s |
| Parked, program ends | **59.2 s** | **55.8 s** |

Three SIM seeds on this layout: 59.2 s, 58.8 s and 59.4 s, each with all 18 sign passes on the correct side and parked. The simulator's own check of the final position found 3 of 4 corners inside the lot for seeds 1 and 2 (0.2 s of contact with a parking limitation during the park) and the car fully inside for seed 3. On the mat the program's check reported all 4 corners inside. The SIM is about 3.4 s slower than the mat run on this layout; laps 2 and 3 take 10.6 s in the SIM and 9.8 to 9.9 s on the mat. All SIM runs went through our sim queue (at most three at a time, CPU load checked) and were marked TRUSTED. SIM numbers are simulator results; the mat run is the reference.

**Open it online:** https://blluewave.github.io/WRO-Future-Engineers-2026/docs/arena/

GitHub Pages serves it from the `main` branch.

**Open it locally:** open `docs/arena/index.html` in a desktop browser. The page loads three.js r128 from `cdnjs.cloudflare.com` and OrbitControls from `cdn.jsdelivr.net`, so it needs an internet connection. It remembers the last settings in the browser's local storage.

## What the page does

| Control | What it changes | Rule it follows |
|---|---|---|
| Challenge | Open or Obstacle field | Section 8, p.11 and p.13 |
| New draw / seed | A random layout from a seed number, so the same layout can be rebuilt later | Draw procedures on p.12-16 |
| Driving direction | From the draw, or forced clockwise / counter-clockwise | Rule 9.3, p.17 |
| Open corridors | All 1000 mm, all 600 mm, or each straight drawn separately | Section 8, p.11-12 |
| Obstacle start | Inside the parking lot, or in the middle zone next to it | p.16 |
| 3D / Top view, walls, dimensions | Camera and overlays only | - |

For every draw the side panel lists the steps taken (coin tosses, die roll, cards drawn), the corridor widths, the inner block size, the start section, and whether our car footprint fits inside the start zone. A second table lists every field dimension with its rulebook page.

### Open Challenge draw (p.12-13)

1. Two coin tosses pick the starting section (Figure 7a, p.12).
2. Four coin tosses, clockwise from the start section, set each corridor: heads 1000 mm, tails 600 mm (p.12).
3. A die roll picks the start zone; the page rolls again if the zone falls inside a wall (Figure 7c, p.13).

When the four corridors differ, the inner walls form a rectangle that is no longer centred. That matches rule 13.16 (p.27).

### Obstacle Challenge draw (p.13-16)

1. Two coin tosses pick the section with a single traffic sign (Figure 8b, p.14).
2. One coin toss sets its colour: heads green, tails red (p.14).
3. Card 9 or card 10 is removed from the 36 cards, and one card is drawn per remaining straight, clockwise, without returning cards (Figure 8c, p.14-15).
4. Two more coin tosses pick the starting section, which always holds the parking lot. Signs in that section move to the row nearer the inner wall (Figures 8d and 8e, p.16).

## Every dimension and where it comes from

All page numbers refer to *WRO Future Engineers Category - Game Rules 2026* (55 pages).

| Item | Value | Rule | Page |
|---|---|---|---|
| Game mat | 3200 × 3200 mm (±5 mm) | 13.1 | 26 |
| Racetrack inner size | 3000 × 3000 mm (±5 mm) | 13.1 | 26 |
| Track colour | white | 13.2 | 26 |
| Exterior and interior wall height | 100 mm | 13.3, 13.5 | 26 |
| Wall thickness | not defined by the rules; the page draws 10 mm | 13.7 | 26 |
| Corner lines | 20 mm wide, orange CMYK (0, 60, 100, 0), blue CMYK (100, 80, 0, 0) | 13.9 | 26 |
| Corner line angle | 30 degrees | Figure 11 | 27 |
| Start zone dashed lines | 1 mm, CMYK (0, 0, 0, 30) | 13.10 | 26 |
| Start zone | 200 × 500 mm | 13.11 | 26 |
| Traffic sign seat | 50 × 50 mm, 1 mm line | 13.12, 13.13 | 26 |
| Sign evaluation circle | 85 mm diameter, 0.5 mm line, CMYK (20, 0, 100, 0) | 13.14, 13.15 | 26 |
| Seat rows across a 1000 mm corridor | 400 mm / 200 mm / 400 mm from the inner wall | Figure 11 | 27 |
| Seats per straight | 4 T-intersections and 2 X-intersections | Section 5, Figure 3 | 7 |
| Centre artwork square | 800 mm (the page shows the Blue Wave logo there) | Figure 11 | 27 |
| Open corridor width | 1000 mm or 600 mm (±100 mm at the International Final) | Section 8 | 11 |
| Obstacle corridor width | always 1000 mm (±10 mm at the International Final) | Section 8 | 13 |
| Traffic sign (pillar) | 50 × 50 × 100 mm | 13.19 | 28 |
| Pillars per colour | up to 7 | 13.20 | 28 |
| Red / green pillar colour | RGB (238, 39, 55) / RGB (68, 214, 44) | 13.21, 13.22 | 28 |
| Meaning of the colours | red: keep to the right side of the lane; green: keep to the left | Section 5 | 6 |
| Parking lot limiter | 200 × 20 × 100 mm, magenta RGB (255, 0, 255) | 13.25, 13.27 | 28 |
| Parking lot width | 200 mm | Section 5 | 8 |
| Parking lot length | 1.5 × robot length; 337.2 mm for our 224.8 mm car | Section 5 | 8 |
| Parking lot position | in the starting section, right limiter next to the dotted line | Section 5, Figure 4 | 8 |
| Car placement | footprint fully inside the start zone | 9.7 | 17 |
| Car orientation | front axle toward the next corner in the driving direction | 9.8 | 17 |
| Round length | 3 minutes for each challenge | 9.1, 9.2 | 17 |

With our car the lot leaves (337.2 - 224.8) / 2 = 56.2 mm at each end when the car is centred, and 200 - 111.0 = 89.0 mm across the lot. The panel shows both numbers for the current draw.

## What is not taken from the rulebook

- **Wall thickness.** Rule 13.7 leaves it undefined. The page uses 10 mm.
- **How the direction is drawn.** Rule 9.3 only says the direction is random. The page tosses a coin.
- **Die numbering in the other three sections.** Figure 7c (p.13) draws one section. The page rotates that numbering for the others.
- **Seat of the single sign.** The page places it in the middle column, outer row (the positions on cards 9 and 10). The rules text does not state it.
- **Our car.** The 224.8 × 111.0 × 157.2 mm envelope is the BW-2 car's CAD model (WLtoys 1:28 chassis with the printed body). The built car has not been measured yet; the page will take the measured numbers when we have them.

## Related

- [Arena page](../05-build-test-reproduce.md#arena-page) in Build, test and reproduce explains how this page fits with our simulator and the Webots replays.
- The rulebook: https://wro-association.org/wp-content/uploads/WRO-2026-Future-Engineers-Self-Driving-Cars-General-Rules.pdf

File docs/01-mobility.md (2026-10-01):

# Mobility and mechanical design

Appendix C criterion 1. How the car moves, what limits it, and the numbers we measured on it.

Tags: **MAT** measured on the car on our practice mat; **FIT** fitted from the mat run logs; **CAD** read from the body
model, not measured on the car; **EST** an estimate or a datasheet value; **SIM** our calibrated simulator.

## Summary

- WLtoys 1:28 chassis 284131: one 130-size brushed motor drives all four wheels through a propshaft and front and rear
  differentials; Ackermann front axle on one micro servo.
- The motor runs on a Cytron MD13S from the Pi 5 (PWM and direction). Speed follows the duty on one fitted line,
  v = 5.276 × (duty − 0.1012) m/s, with no measurable effect of the pack voltage (FIT, 1599 samples, rms 0.075 m/s).
- The steering reaches 30° to the left and only 22° to the right at the wheels (MAT). Both programs plan every turn
  with the lock of its own side.
- The car understeers more as it goes faster: the effective wheelbase R × tan(steering angle) grows from 137 mm at
  0.2 m/s to 281 mm at 1.7 m/s (FIT, 2694 corner samples). The programs steer with the value for the current speed.
- The printed BW-2 body holds the lidar with its scan plane 50 mm above the mat and the camera on a 16° wedge.

## Sources for this page

| Source | What it holds |
|---|---|
| `src/profiles/wltoys_bw2.json` | the car's calibration: pins, servo pulses, motor start duty, lidar mounting, the notes of each mat measurement |
| `src/profiles/plant_mat1001.json` | motor, brake and steering model fitted to 20 mat run logs of 2026-09-30 and 2026-10-01 |
| run `20261001-161301.412-open_v7` | the 14.7 s Open run (speeds, accelerations, loop timing) |
| run `20261001-222840.106-obs_v17` | the 55.8 s Obstacle run |
| BW-2 body model (`Models/`) | dimensions, mass estimate, part layout |

## Why this chassis

The electronics come from a Hiwonder MentorPi A1 robot kit. That kit drives each rear wheel with its own motor and sets
their speeds separately. Rules 11.5 and 11.13 do not allow drive motors connected to the wheels independently, and
equal speeds in software do not change that. On 2026-09-23 we moved the electronics onto a WLtoys 1:28 chassis: one
motor, one propshaft, mechanical differentials front and rear (four-wheel drive) and one steering servo, which meets
rule 11.3 as built.

What we gave up: the kit's motors have encoders, the WLtoys motor has none. The car's speed and travel therefore come
from the lidar (an absolute position about ten times a second) and from a fitted model of the motor, described below
and in [Power and sensors](02-power-and-sensors.md#speed-without-an-encoder).

## Size, mass and the parking lot

<p align="center">
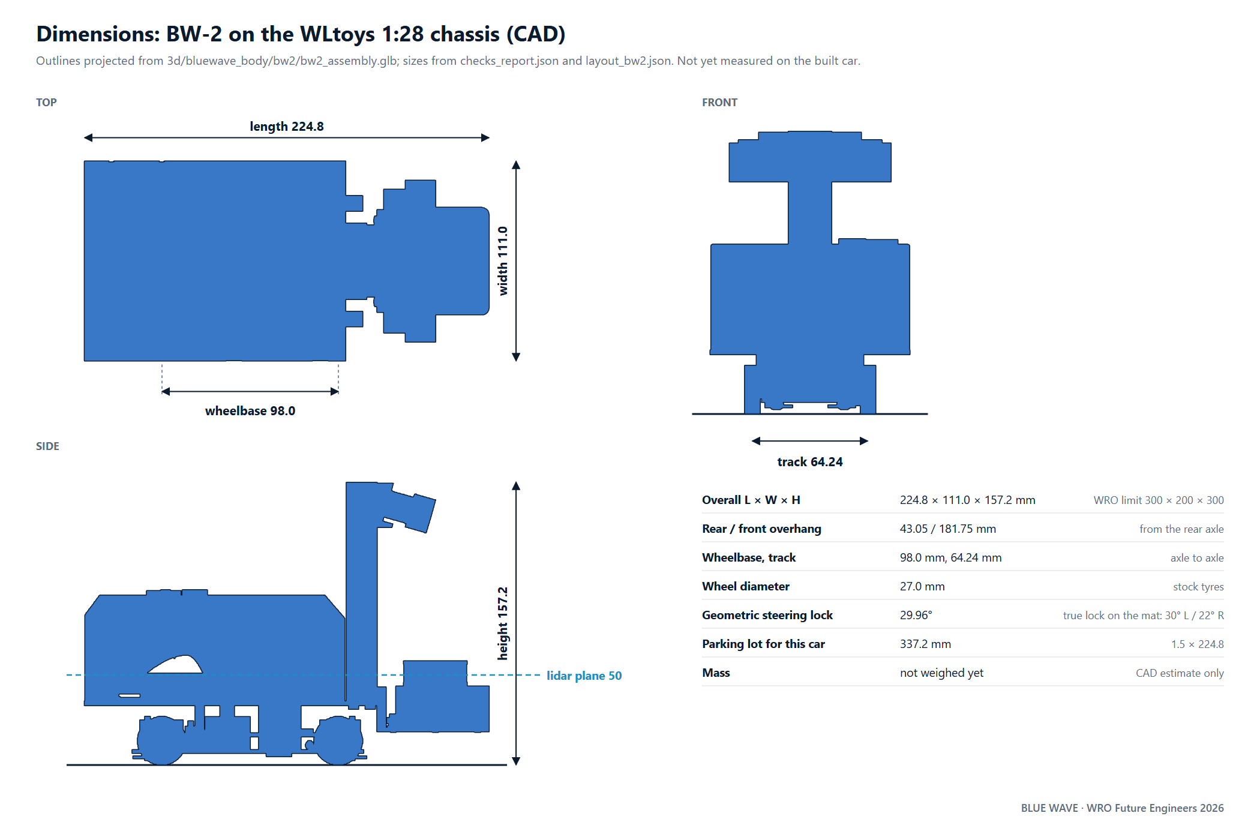
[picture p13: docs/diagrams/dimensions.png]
Top and side views of the car with the CAD dimensions: 224.8 mm long, 111.0 mm wide, 157.2 mm high, wheelbase 98.0 mm, track 64.24 mm, lidar plane 50 mm above the mat
  
</p>

| Quantity | Value | Tag |
|---|---|---|
| Length | 224.8 mm: from 43.05 mm behind the rear axle to 181.75 mm ahead of it | CAD |
| Width | 111.0 mm | CAD |
| Height | 157.2 mm, set by the camera on the tower | CAD |
| Wheelbase, axle to axle | 98.0 mm | CAD |
| Track | 64.24 mm | CAD |
| Wheel diameter | 27.0 mm | CAD |
| Mass | 721.3 g (infill estimate) to 737.1 g (solid bound) for the full CAD model, which still includes three printed parts that are not on the car: E-deck 27.1 g, servo cradle 6.0 g, four lock struts 0.3 g each (CAD). Not yet weighed | CAD, EST |
| Centre of gravity | 59.5 mm ahead of the rear axle, 56.3 mm above the mat, for the same full CAD model | CAD, EST |
| Parking-lot length for this car | 337.2 mm = 1.5 × 224.8 mm | CAD |

Rule 11.1 allows 300 × 200 × 300 mm and rule 11.2 1.5 kg, so the car is inside both with room to spare. The car has no
moving body parts, so its size is the same at the start, during the lot exit and in the park (Q&A ruling of
2026-08-11). A Q&A ruling of 2026-09-18 says the lot length counts only the part of the car within 10 cm of the mat
that can touch the magenta walls. The Obstacle program's lot model is 337.4 mm, 1.5 × (43.1 + 181.8) mm with the
overhangs as rounded in the layout file the programs read, and the program corrects the lot's position from the
limitations the lidar sees on the last lap.

The static stability factor, track / (2 × CG height), is 0.571, which puts the rigid tipping point at a lateral
acceleration of 5.60 m/s² (EST from the CAD centre of gravity of the full model). The chassis rides on its stock springs, and body roll
lowers that point: the Open program's notes put it at 3.83–4.54 m/s² (EST). This is why the fastest Open preset we
tried in SIM (3.4 m/s² planned in corners) was never run on the mat.

## Drive train

| Element | Detail | Tag |
|---|---|---|
| Motor | WLtoys stock 130-size brushed motor, the only drive motor | |
| Transmission | propshaft to front and rear differentials, all four wheels driven | |
| Driver | Cytron MD13S (6–30 V, 13 A): PWM on Pi GPIO12 (header pin 32), direction on GPIO16 (pin 36), signal ground on pin 34 | |
| PWM | 490 Hz, software PWM through `lgpio`: the Pi 5's hardware PWM channel returned an error on this pin | MAT |
| Direction | DIR low = forward (checked on the mat 2026-09-30; an older wiring note said the opposite) | MAT |
| Brake | PWM low with DIR held: the MD13S shorts the motor | MAT |

Safety in the drive code: every stop sets PWM to zero, then DIR low; a 200 ms watchdog stops the motor if commands stop
arriving; a guardian zeroes the PWM if the program dies; the motor is cut after 0.8 s of stall.

### Speed model

We fitted the motor on the mat logs rather than on a bench, because the mat is where the car must be right.

| Quantity | Value | How | Tag |
|---|---|---|---|
| Start from standstill | breakaway duty 0.1362; a kick of duty 0.1558 for 60 ms; dead band 0.1187 | duty sweep test, 2026-09-30 | MAT |
| Steady speed | v = 5.276 m/s × (duty − 0.1012) | 1599 lidar speeds on straights, rms 0.075 m/s; the previous line (4.49, 0.1187) had rms 0.271 m/s | FIT |
| Pack voltage | no measurable effect on speed per duty (exponent 0.0) | same fit, 20 runs on different packs | FIT |
| Speed-up lag | time constant 0.56 s | same fit | FIT |
| Braking, PWM low | 2.08 m/s² over all runs; at least 1.6 m/s² measured from 0.48 m/s | same fit; stop test | FIT, MAT |
| Coasting stop from 0.25 m/s | 80–180 mm | coast test | MAT |
| Fastest seen | 1.39 m/s, peak duty 0.438, in the 14.7 s Open run | lidar speed, run `20261001-161301.412-open_v7` | MAT |

The voltage result changed a program: see [battery compensation](04-engineering-decisions.md#battery-compensation-that-over-corrected).

## Steering

| Quantity | Value | Tag |
|---|---|---|
| Servo | WLtoys stock micro servo on the RRC Lite PWM port 3 | |
| Pulse map | centre 1441 µs, 22.4 µs per degree, limits 853–2194 µs | MAT |
| Straight ahead | at servo −4°: every program adds a trim of −4° to each command | MAT |
| Servo command range | ±26° | MAT |
| True wheel angle at full lock | 30° left, 22° right | MAT |
| Geometric lock of the linkage | 29.96° | CAD |
| Servo speed | 85.6°/s, 0.35 s from centre to lock; 0.05 s from servo to yaw | MAT, FIT |
| Full-lock radius at 0.2 m/s | left 237 mm (turn test); right 339 mm (22° on the 137 mm effective wheelbase) | MAT, calculation |

The trim and the unequal lock have the same cause: with the servo centred, the wheels point about 4° to the left. A
±26° servo command on top of the −4° trim gives 30° on the left and 22° on the right. Counter-clockwise runs hid the
trim, because left turns still reached their radius; clockwise runs lost about half of each right turn. The story and
the run IDs are in [Engineering decisions](04-engineering-decisions.md#steering-trim-and-the-unequal-lock).

Mechanical fix not yet made: re-centring the servo horn would give roughly the same lock on both sides.
We have not done it because both main programs are tuned on the present geometry.

### Understeer against speed

At 0.2 m/s the car turns at full left lock on a 237 mm radius. With the 98 mm axle-to-axle wheelbase, Ackermann geometry would predict 98 / tan 30° = 170 mm. The effective wheelbase L = R × tan(true steering angle) fits the car
better, and it grows with speed:

<p align="center">
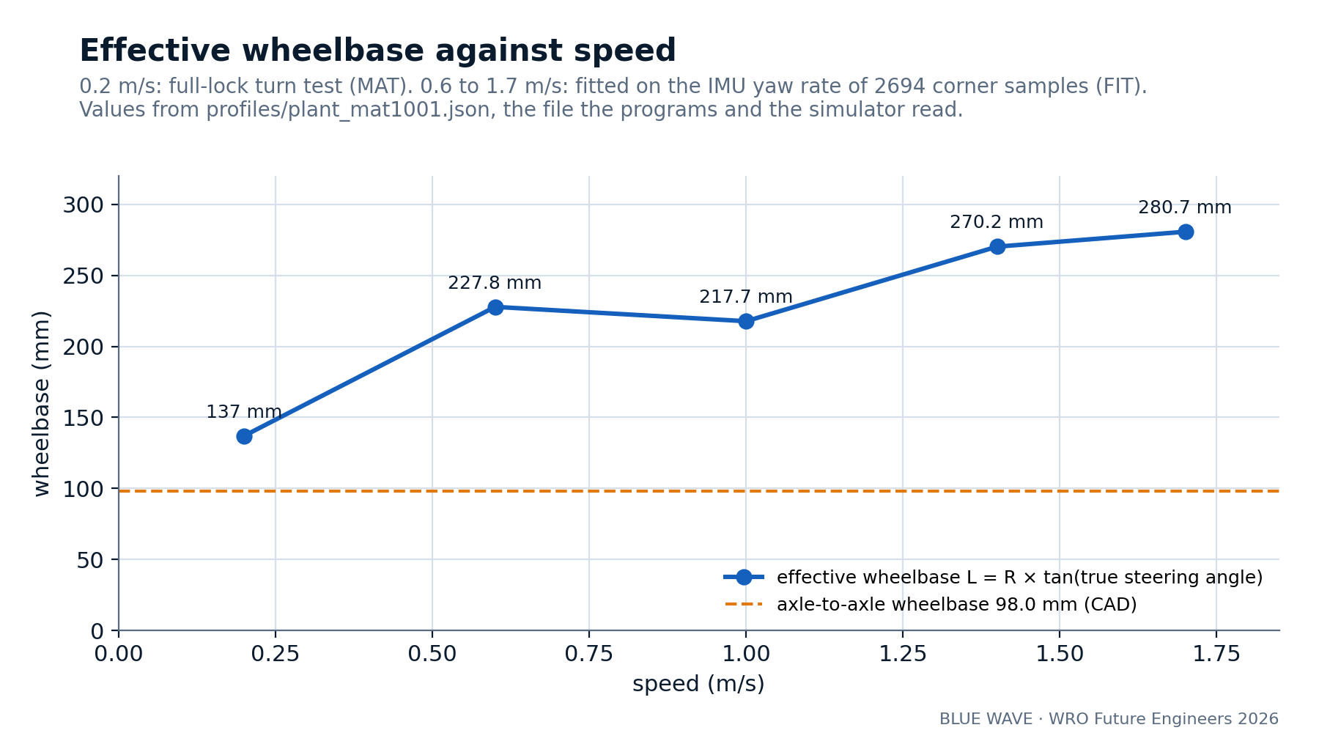
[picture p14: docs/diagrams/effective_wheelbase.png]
Effective wheelbase against speed: 137 mm at 0.2 m/s, 228 at 0.6, 218 at 1.0, 270 at 1.4 and 281 mm at 1.7 m/s; axle wheelbase 98 mm for reference
  
</p>

| Speed (m/s) | 0.2 | 0.6 | 1.0 | 1.4 | 1.7 |
|---|---|---|---|---|---|
| Effective wheelbase (mm) | 137 | 227.8 | 217.7 | 270.2 | 280.7 |

FIT on the IMU yaw rate of 2694 corner samples at 0.5 m/s or more (yaw-rate rms 0.124 rad/s); the 0.2 m/s point is the
turn test. The same fit found a steering bias of +4.05° in corners at 0.6–1.2 m/s, the trim above.

Each program asks for the steering angle atan(L(v) / R) with L taken at the present speed. Before this curve we used one
value, 210 mm, measured at 0.8–1.0 m/s. In the calibrated simulator every arc at 1.3–1.5 m/s then came out about 30 %
too wide. The parking legs run slowly, on the 137 mm value.

### Corner speed

The Open program sets each arc's speed to √(a × R), with a = 2.6 m/s² in the preset of the 14.7 s run, and brakes
before the arc at a planned 1.8 m/s². The Obstacle program plans at 1.1 m/s², 0.50 m/s in lap 1 and 0.80 m/s in laps
2 and 3. The highest horizontal acceleration the IMU logged was 0.56 g in the Open run and 0.42 g in the Obstacle run,
with no contact in either (MAT).

## The BW-2 body

We designed the body around three rules for this car: the lidar's scan plane must sit below the top of the 100 mm
walls; the camera's pitch must not change when the car is handled; and the battery must come out without tools. The
body sits on the chassis on a printed deck (D1).

<p align="center">
  Exploded CAD render of the BW-2 body: deck, frame and battery tray, tower with the lidar bay and camera mast, camera wedge, shell
  <br><sub>CAD render, not a photo.</sub>
</p>

Printed parts on the car (PETG, 0.4 mm nozzle). The colours are the ones we printed; the file names keep the colour of
the CAD model so that they match our recorded file hashes.

| File | Part | Printed colour | Layer / walls / infill | Print time, mass (EST) |
|---|---|---|---|---|
| `01_D1_deck_darkgrey.stl` | deck that mounts on the chassis | blue | from the first body | 40.9 g |
| `02_L1_frame_battery_tray_darkgrey.stl` | frame and battery tray, Pi 5 bosses | white | 0.2 mm / 4 / 40 % | 42 min, 14.0 g |
| `04_tower_blue.stl` | tower: camera mast and lidar bay in one print, 4 datum pads | blue | 0.2 mm / 4 / 40 %, 5 mm brim | 115 min, 33.3 g |
| `05_shell_blue.stl` | shell: flat roof, 1.2 mm skin | blue | 0.2 mm / 3 lines of 0.40 mm / 15 % | 164 min, 60.6 g |
| `07_cam_wedge_16deg_darkgrey.stl` | camera wedge, 16° | dark grey | 0.12 mm / 5 / 50 % | 32 min, 7.9 g |

| Feature | Value | Tag |
|---|---|---|
| Lidar position | on the centre line, 152.0 mm ahead of the rear axle | CAD |
| Lidar scan plane | 50.0 mm above the mat (field walls are 100 mm high) | CAD |
| Lidar sector blocked by the tower | 132.35°–227.7° (rear) | CAD |
| Camera lens | 149.4 mm ahead of the rear axle, 138.28 mm above the mat | CAD |
| Camera pitch | 16° from the wedge in the model; 19.61° measured on the car on 2026-10-01 | CAD, MAT |

The programs use the measured 19.61°. The difference from the 16° wedge is not explained yet; the pitch check before
every session (see [Power and sensors](02-power-and-sensors.md#calibration)) catches any change.

Design checks on the full CAD assembly (2026-09-25): 91 part pairs with no clearance violation (tightest gap 0.35 mm),
93 contacts with no part floating, every print file a closed single solid, the camera's view clear of the body by
22.1 mm, 18 of 18 cable routes clear, and every screw head reachable in build order.

<sub>[Back to the README](../README.md)</sub>

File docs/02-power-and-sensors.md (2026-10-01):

# Power and sensor architecture

Appendix C criterion 2. Where the power goes, what each sensor gives the car, where it sits and why, how we calibrate
it, and what the code does when a part fails.

Tags: **MAT** measured on the car; **FIT** fitted from mat run logs; **CAD** from the body model; **EST** estimate or
datasheet value; **SIM** simulator.

## Summary

- One 7.4 V pack feeds everything through one power switch: the RRC Lite board (which powers the Pi 5 over USB-C) and
  the MD13S motor driver.
- Sensors: an LD19 lidar 50 mm above the mat, an HP60C colour camera pitched 19.61° down, and the RRC Lite's IMU.
  There is no wheel encoder.
- The lidar gives the position: walls and sign pillars from one revolution, about ten times a second. The camera only
  gives colour. The IMU gives the heading between scans.
- Speed comes from a model of the motor, corrected by the lidar at every scan; in the 14.7 s Open run its median error
  against the lidar was 0.01 m/s (MAT).

## Power

<p align="center">
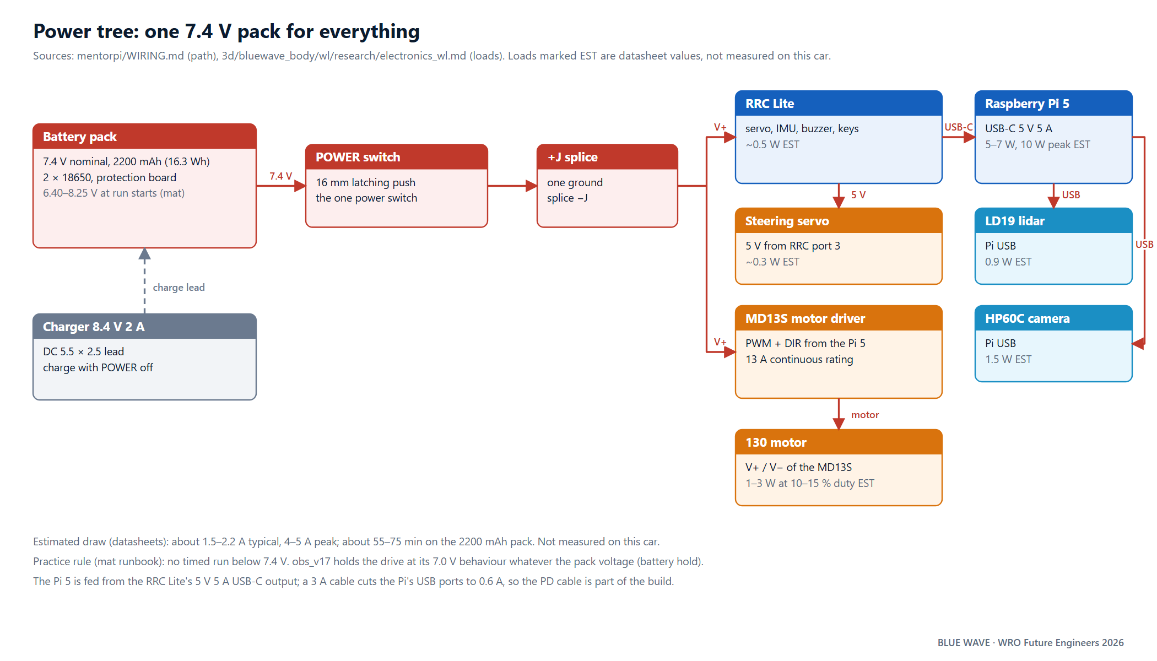
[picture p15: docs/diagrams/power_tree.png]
Power tree: 7.4 V pack, 16 mm power switch, a positive splice to the RRC Lite and the MD13S, one negative splice; the RRC Lite feeds the Raspberry Pi 5 over a 5 V 5 A USB-C cable; the Pi's USB ports feed the LD19 lidar and the HP60C camera
  
</p>

| Element | Detail | Tag |
|---|---|---|
| Pack | Hiwonder 7.4 V, 2200 mAh, 10C (two 18650 cells with a protection board), 16.3 Wh | EST (listing) |
| Charging | 8.4 V 2 A charger on a DC 5.5 × 2.5 mm lead, with the power switch off | |
| Power switch | 16 mm latching push switch on the pack's positive lead: the only switch (rule 9.10) | |
| Distribution | after the switch, one positive splice to the RRC Lite power input and the MD13S V+; one negative splice for both | |
| Pi 5 supply | from the RRC Lite's 5 V 5 A USB-C output, with a 5 A cable: a 3 A cable cut the Pi's USB ports to 0.6 A | |
| Motor current | returns on the MD13S power negative, not on the Pi's signal ground | |

Wiring rule we keep: never unplug the MD13S negative alone while its signal lines are connected to the Pi, because the
motor current would then look for a path through the Pi and the RRC Lite.

### Load budget

| Load | Power | Tag |
|---|---|---|
| Raspberry Pi 5 | 5–7 W, 10 W peak | EST (datasheet) |
| LD19 lidar | 0.9 W | EST (datasheet) |
| HP60C camera | 1.5 W | EST (datasheet) |
| RRC Lite with IMU | about 0.5 W | EST |
| Steering servo | 0.3 W | EST |
| Drive motor | 1–3 W at 10–15 % duty | EST |

Total current is about 1.5–2.2 A in normal driving and 4–5 A at peaks (EST), which puts the run time of the 2200 mAh
pack at about 55–75 min (EST). A round lasts at most three minutes, so the limit in practice is the pack voltage, not
its capacity.

### Pack voltage

We start mat runs at 7.4 V or more and charge below that. The first logged pack voltage of the finished runs of
2026-09-30 and 2026-10-01 ranges from 6.40 V to 8.25 V (MAT), because some development runs were made on a low pack.

The motor driver code scales the duty by v_ref / V_pack (v_ref = 8.0 V) to keep the speed the same on any pack. The
mat fit found that this car's speed per duty does not fall with the pack (FIT, exponent 0.0), so the scaling made the
car faster on a low pack: × 1.31 at 6.1 V. The Obstacle program `obs_v17` therefore holds the scaling at its 7.0 V
value for the whole run. Run IDs and the effect on the park: [Engineering decisions](04-engineering-decisions.md#battery-compensation-that-over-corrected).

## Pin map

Pin numbers are the Raspberry Pi 5 header pins (1–40). Values from `src/profiles/wltoys_bw2.json`.

| Signal | Pi 5 pin | GPIO or port | Other end | Setting |
|---|---|---|---|---|
| Motor PWM | 32 | GPIO12 | MD13S PWM | 490 Hz, software PWM (`lgpio`) |
| Motor direction | 36 | GPIO16 | MD13S DIR | low = forward |
| Signal ground | 34 | GND | MD13S GND | |
| Start button | 11 and 9 | GPIO17 and GND | 12 mm push button | internal pull-up; press at least 30 ms, then release |
| Body ID strap | 29 and 30 | GPIO5 and GND | jumper | present = this chassis; read by the code at start |
| Steering servo | | RRC Lite PWM port 3, jumper at 5 V | servo | centre 1441 µs, 22.4 µs per degree, 853–2194 µs |
| RRC Lite | USB-A | serial, 1,000,000 baud | RRC Lite USB-C | |
| Lidar | USB-A | CH340 serial, 230,400 baud | LD19 | |
| Camera | USB-A | | HP60C USB-C | |

<p align="center">
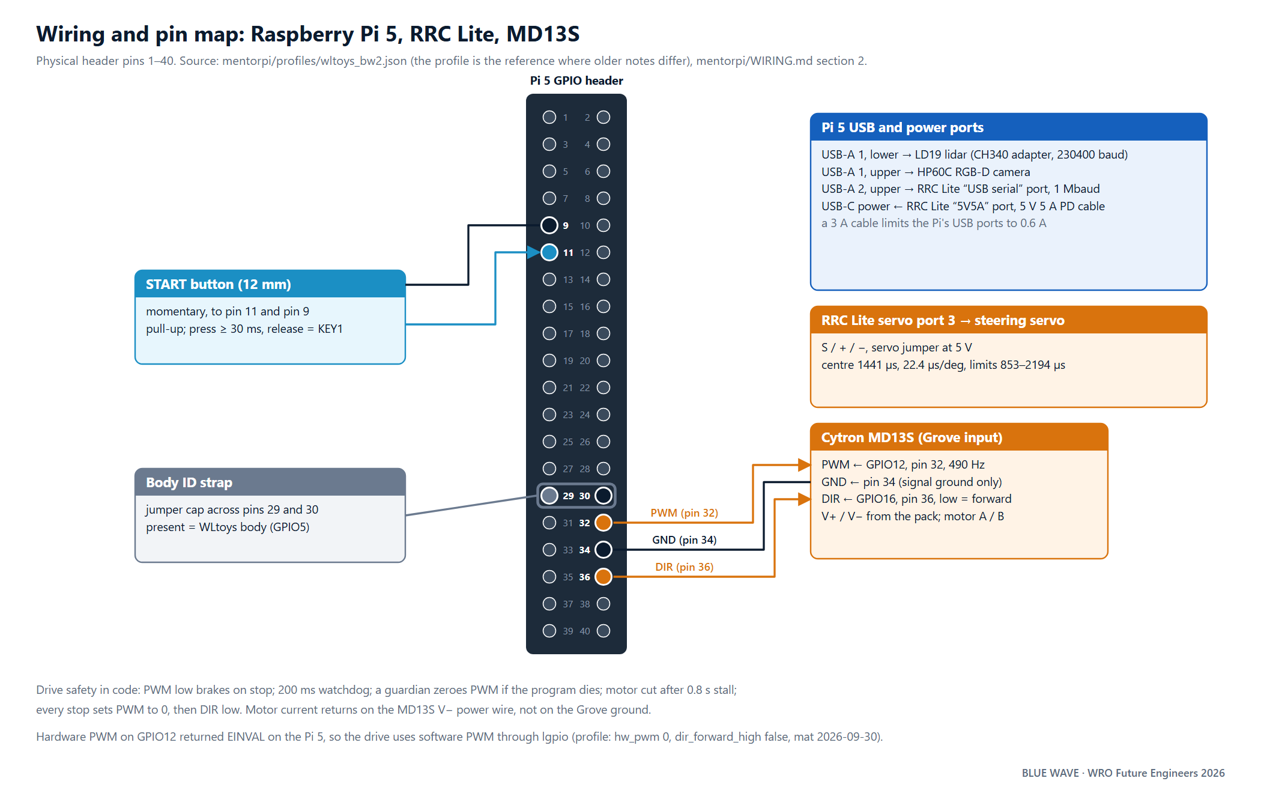
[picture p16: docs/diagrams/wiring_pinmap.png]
Pin map of the Raspberry Pi 5 header: GPIO12 pin 32 PWM and GPIO16 pin 36 direction to the MD13S, pin 34 ground, GPIO17 pin 11 start button, GPIO5 pin 29 body strap; USB to the RRC Lite, the LD19 and the HP60C; RRC Lite PWM port 3 to the steering servo
  
</p>

Full schematic: [Schemes](../Schemes/README.md).

## Sensors

<p align="center">
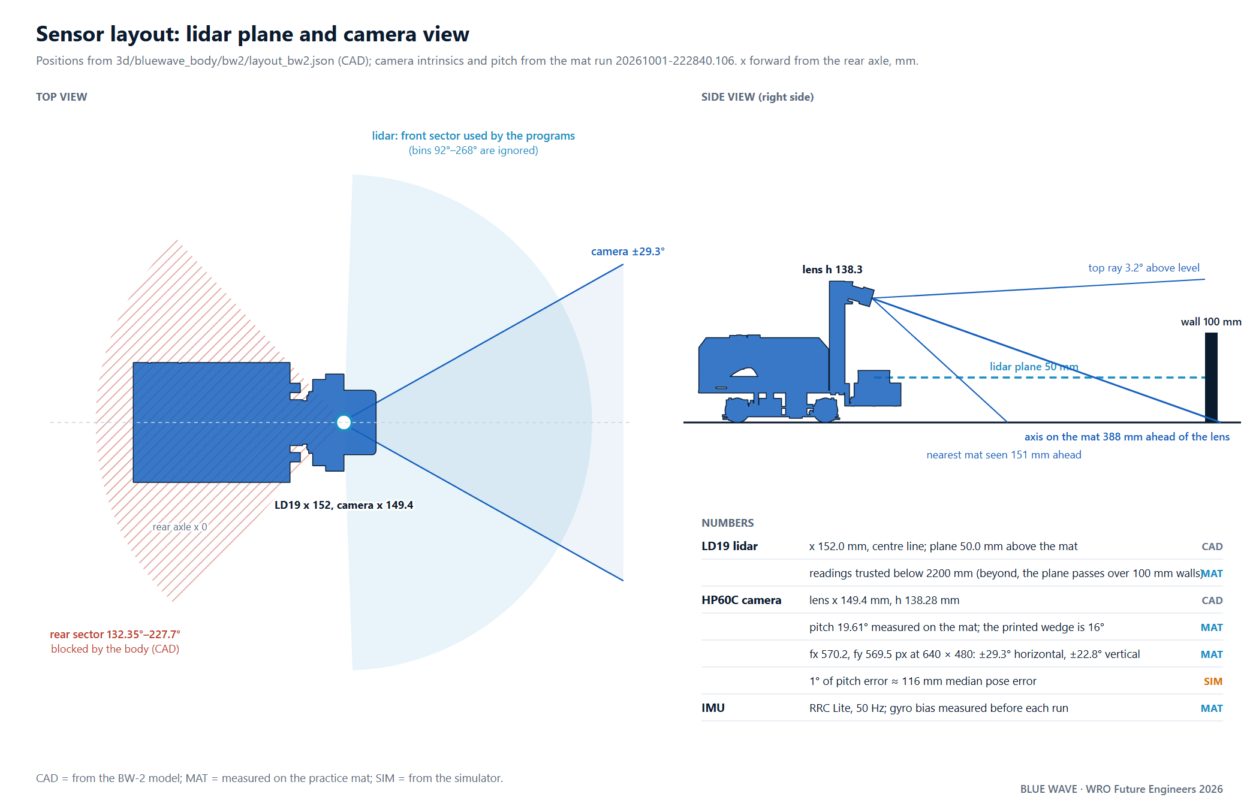
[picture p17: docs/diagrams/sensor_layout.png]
Sensor layout seen from the side and from above: lidar at 152 mm ahead of the rear axle with its scan plane 50 mm above the mat, below the top of the 100 mm wall; camera lens 138 mm high, pitched 19.6 degrees down, field of view plus and minus 29.3 degrees; blocked rear lidar sector
  
</p>

### LD19 lidar

| Quantity | Value | Tag |
|---|---|---|
| Position | centre line, 152.0 mm ahead of the rear axle | CAD |
| Scan plane | 50.0 mm above the mat; the field walls are 100 mm high | CAD |
| Rate | 598–599 rpm (about 10 scans/s), 1° bins | MAT |
| Mounting in the code | clockwise, offset 180° (scan index 0 is the car's rear) | MAT |
| Range used | readings up to 2200 mm; beyond that the plane can pass over a far wall | MAT |
| Sector used | the front half of the scan; the tower blocks part of the rear (132.35°–227.7°, CAD) | MAT, CAD |

Why 50 mm: on the kit's own mount (2026-09-22) the LD19 scanned above the walls and the sign pillars. A green pillar
25 cm and then about 70 cm ahead never appeared, and a wall 40 cm to the left was missing; the lidar read 2.5–4.3 m,
the room behind the field. The body puts the plane at half the wall height, so walls and pillars are both in it.

What the lidar gives the programs (module `lidar_perc.py`): wall segments, pillar clusters (the signs are 50 × 50 mm),
and the parking-lot limitations, all from one revolution. The Open program reads the wall ahead, both side walls and
the island's inner corner. The Obstacle program fits the wall points to the field map for its position: 551 fits in
the 55.8 s run, 6 rejected, median fit error 5.5 mm (MAT, run `20261001-222840.106-obs_v17`).

### HP60C camera

| Quantity | Value | Tag |
|---|---|---|
| Colour stream | 640 × 480 at 14.2–14.3 frames/s in the runs | MAT |
| Intrinsics | fx 570.169, fy 569.464, cx 325.87, cy 238.096 px | MAT |
| Horizontal field of view | ±29.3° | MAT (from fx) |
| Latency | 0.09 s from exposure to the program | MAT |
| Lens | 149.4 mm ahead of the rear axle, 138.28 mm above the mat | CAD |
| Pitch | 19.61° down | MAT, 2026-10-01 |

The camera is read through Hiwonder's driver, which runs in the vendor's ROS 2 container on the Pi; our code reads its
colour stream on the same machine.

The camera does one job: colour. A pillar the lidar has found is paired with a red or green blob at the same bearing,
at the pose the frame was taken. Pairing by bearing does not depend on the pitch. Hue limits (OpenCV, 0–180) set on the
mat of 2026-10-01: red 10–180 wrapping through 0, green 38–92, magenta 135–180. The parking limitations on that mat
read hue 173–178, which is why the red and magenta ranges overlap and the program tells a limitation from a sign by
its distance from the outer wall (a limitation stands 200 mm out, signs 400 or 600 mm).

The ±29.3° field of view decides what the camera can read. A sign 30–60° off the camera axis is not seen until it is
about 250 mm away, beside the car: how we found that and what we changed is in
[Engineering decisions](04-engineering-decisions.md#the-camera-could-not-see-the-sign).

Why we do not use the depth stream: on 2026-09-22 it gave no returns from the white mat, missed most of the black
walls, and over-read a pillar at 1.25 m as 1.43 m. The lidar measures the same things better.

### IMU

The RRC Lite reports its 6-axis IMU at 50 Hz (MAT). The gyro bias is measured with the car still at the start of each
session (−0.2991 °/s before the 55.8 s run, MAT) and subtracted. The heading sums every sample × 0.02 s.

### Speed without an encoder

| Program | Speed source | Accuracy |
|---|---|---|
| Open (`BEST_OPEN_14s`) | observer: the fitted duty line run on the duty the motor really gets, corrected at every scan by the rate at which the wall ahead approaches | median error 0.01 m/s, 90th percentile 0.058 m/s, scale 1.014 (MAT, run `20261001-161301.412-open_v7`) |
| Obstacle (`obs_v17`) | the lidar wall fit for position; gyro and duty model between scans | median fit error 5.5 mm (MAT) |

The lidar speed alone goes stale in arcs: there the wall ahead turns away. In SIM laps 2 and 3 it was not fresh about
70 % of the time, which is why the Open program runs the motor model and uses the lidar to correct it.

### Timing

| Loop | Value | Tag |
|---|---|---|
| Open control loop | 40 Hz; loop time median 26.6 ms, 99th percentile 32.0 ms | MAT |
| Age of the lidar scan used | median 14.2 ms, 99th percentile 26.8 ms | MAT |

## Calibration

| Calibration | How | When |
|---|---|---|
| Camera pitch | car still, one pillar centred with its near face 500 mm from the front bumper; the test fits the pitch and must answer GO | before each session and after any knock |
| Gyro bias | car still, averaged | start of each session |
| Colours | hues of red, green and the magenta limitations read under the venue light | on arrival at a new field |
| Lidar direction | the lidar direction test | after any lidar work |
| Motor start and speed line | duty sweep from standstill; speed line fitted from run logs | after a motor or driver change |
| Steering | servo sweep and turn-radius test at 0.2 m/s; straight-line trim | after any steering work |
| Field check | car still at the start; the scan must match the standard field | before a round |

One degree of camera pitch error moved the pose by a median 116 mm in SIM for our camera-only localisation, and the
kit's camera mount moved about 10° in one day. The keyed wedge on the tower and the pitch check are the answer.

## Failure modes and how the code handles them

| Failure | Detection | Response |
|---|---|---|
| Lidar mounted or configured differently from the calibration | direction and offset check at start | the Open program halts before the car moves |
| Program thread stalls | each motion command carries a dead-man time; 200 ms motor watchdog | the motor stops |
| Program dies | a guardian in the motor driver code | PWM to zero, DIR low |
| Motor stalled | no movement for 0.8 s | motor cut |
| RRC Lite stops streaming (seen at full lock on a standing car with a low pack) | IMU data older than 0.35 s | hold, reopen the board; standing steering limited to 12° |
| Servo stops following commands after a full-lock corner | wall ahead closing by 150 mm or more in 0.4 s while the yaw is under 30 % of what the steering asks; or the gyro turning against the steering for 0.35 s | reopen the board |
| Wall or sign too close for the command | the lidar shield projects every command | slow, steer away or brake (16, 5 and 1 times in the 55.8 s run) |
| Sign found by the lidar but no colour read | sign seat without a camera vote | turn the nose toward it and read where the map puts it |
| Parking limitation read as a red sign | blob within 270 mm of an outer wall | ignored as a sign |

## Sensing bugs we fixed

| Date | Symptom | Cause | Fix |
|---|---|---|---|
| 2026-09-30 | centring pushed the car toward the walls; the shield braked on walls that were not there | lidar direction set to counter-clockwise: left and right were mirrored against the steering and the gyro. The proof: at every corner stop the open side in the scan was opposite the side the car turned to | clockwise, offset 180°, and the start-up check above |
| 2026-09-30 | a corner exited 17° off and the car drove into the island | the heading used only the latest gyro value and dropped any gap of 0.2 s or more: a 0.26 s stall lost about 20° | sum every IMU sample × 0.02 s |
| 2026-09-30 | the whole program froze for 0.5 s every 5.4 s | the body-ID strap opened and closed the GPIO chip on the main loop | read the strap once and keep it |
| 2026-10-01 | the route went into the parking lot | the lot's limitations (hue 173–178) passed the red mask | the 270 mm outer-wall band and the measured hue ranges |

<sub>[Back to the README](../README.md)</sub>

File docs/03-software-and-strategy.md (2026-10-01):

# Software architecture and obstacle strategy

Appendix C criterion 3. How the code is organised, how the two challenge programs drive, and where every constant
comes from.

Tags: **MAT** measured on the car; **FIT** fitted from mat run logs; **SIM** simulator; **CAD** body model.

## Summary

- All code runs on the Raspberry Pi 5 in Python. The RRC Lite keeps its stock firmware and only executes servo, buzzer
  and IMU commands sent over USB serial.
- One `Robot` interface (`bluewave/hw.py`) is the same on the car and in our simulator, so a program runs unchanged in
  both.
- Open Challenge, `programs/BEST_OPEN_14s.py`: lidar in the corridor frame, one constant-radius arc per corner, a
  braking speed plan on a speed observer, lap-1 corridor map replayed in laps 2 and 3. Mat: 14.7 s.
- Obstacle Challenge, `programs/obs_v17.py`: lidar wall fit for the pose, signs on the 24 legal seats with the colour
  from the camera, a lane per sign, the lot exit and the parallel park on the real steering lock of each side. Mat:
  55.8 s with a full park.
- Race mode blocks every radio, waits for the one start button, and runs the program chosen for the round.

## Where the code runs

| Place | What | Files (in `src/`) |
|---|---|---|
| Pi 5, the robot package | hardware drivers, perception, localisation, planning helpers, safety, logging | `bluewave/` (43 Python files) |
| Pi 5, the challenge programs | one file per program, each with `run(robot, params, log, stop)` | `programs/BEST_OPEN_14s.py` (1,998 lines), `programs/obs_v17.py` (1,945 lines) |
| Pi 5, race mode | start-up script and the race entry point | `os/bluewave-mode.sh`, `os/bluewave-race.service`, `race/race_main.py` |
| Pi 5, vendor container | Hiwonder's HP60C driver (ROS 2); our code reads its colour stream locally | vendor software, unchanged |
| RRC Lite (STM32F407) | servo pulses, IMU stream, buzzer, keys | Hiwonder firmware, unchanged |
| Laptop (development only) | deploy, run and pull logs; simulator; plant fit | `tools/` |

### Modules of the robot package

| Module | Role | Hardware |
|---|---|---|
| `hw.py` | the `Robot` object: drive, steer, IMU, lidar, camera, beeps, keys; speed envelope | all |
| `rrc.py` | RRC Lite serial protocol (frame, CRC, servo, IMU, keys, buzzer) | RRC Lite |
| `motor.py` | MD13S PWM and direction, brake, watchdog, stall cut, guardian | MD13S, motor |
| `speed.py` | speed without an encoder: lidar pose and duty model | LD19, motor |
| `lidar.py` | LD19 driver | LD19 |
| `lidar_perc.py` | walls, pillars and parking limitations from one revolution; pillar-to-blob pairing by bearing | LD19, HP60C |
| `camera.py`, `vision.py` | frame grabber; colour masks and blobs | HP60C |
| `field.py` | the field map: walls, island, the 24 sign seats, the lot | |
| `loc.py`, `seats.py` | localisation; sign seats from lidar position and camera colour | LD19, HP60C |
| `park.py` | lot exit and parallel-park legs on the car's true footprint | drive, steering |
| `shield.py` | lidar check of every drive command | LD19 |
| `blackbox.py` | 50 Hz IMU record into the run file | IMU |
| `analyze.py` | after a run: where and why the car touched something | |
| `params.py` | parameters with defaults; the car's calibration file over them | |
| `mock.py` | simulator with the same interfaces | |

### Parameters and logs

A program's settings are layered: the program's defaults, then a named preset, then the car's own values for that
program, then the values given for one run. The car's calibration is `profiles/wltoys_bw2.json`; the fitted motor and
steering model is `profiles/plant_mat1001.json`.

Every run writes one log file named `<date>-<time>-<program>.jsonl`: the parameters it ran with, every program event
(laps, sign reads, corner arcs, Q stops, park legs, the end), telemetry at 20 Hz and the IMU at 50 Hz. The run IDs on
these pages are those file names.

## Race mode

```mermaid
flowchart TD
    P["Power switch on"] --> M{"mode file = race?"}
    M -->|"no"| D["development mode: radios on, console"]
    M -->|"yes"| R["rfkill block all: every radio off (rule 11.10)"]
    R --> L["race_main: open the hardware, load the round's program, compute its plans"]
    L --> B["two beeps = READY"]
    B --> K{"start button pressed and released?"}
    K -->|"no"| K
    K -->|"yes"| X["run the program; log to the run file"]
    X --> E["stop, one long beep"]
```

The program for each challenge and the challenge of the round are set in the car's parameters before the round (`race.programs`, `race.challenge`). Plans that take seconds of
Python on the Pi, such as the lot exit, are computed before READY, so nothing slow sits between the start button and the
first metre. A long press of the board's second key returns the car to development mode.

## Open Challenge: `BEST_OPEN_14s`

<p align="center">
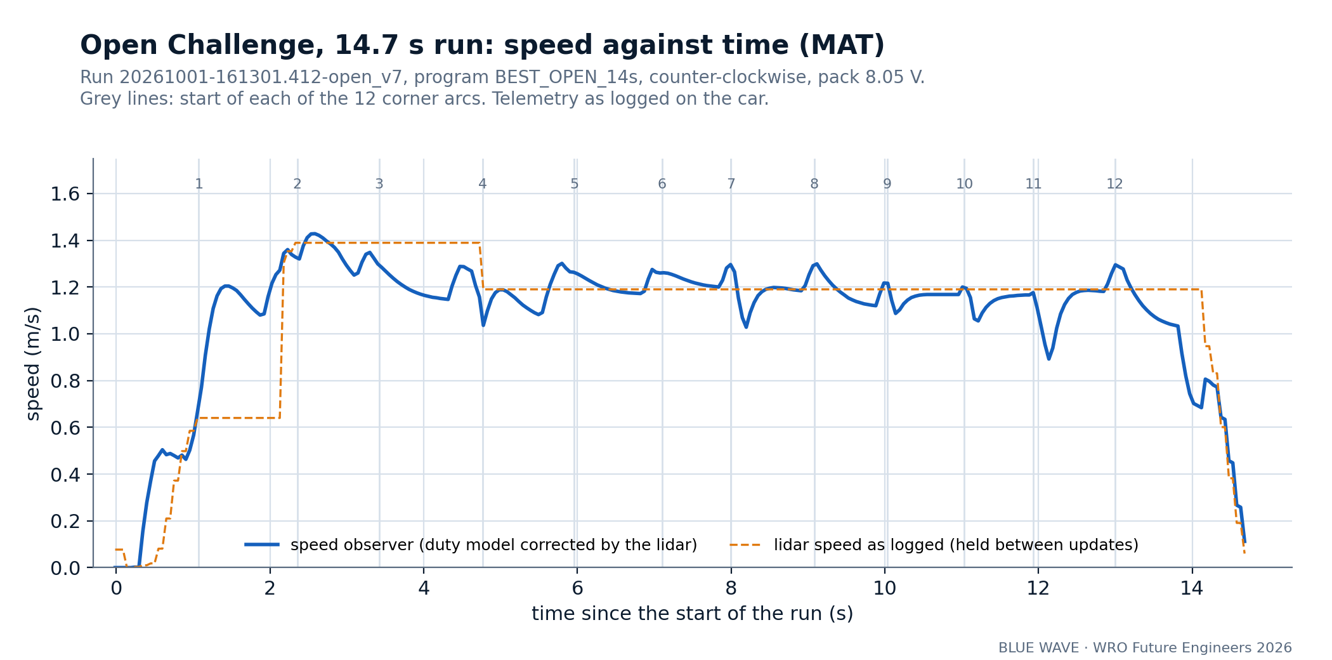
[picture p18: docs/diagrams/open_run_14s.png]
Speed against time in the 14.7 s Open run, from the car's log: speed observer and lidar speed, with the start of each of the 12 corner arcs marked
  
</p>

### Perception in the corridor frame

Each lidar scan is rotated by the gyro heading at the scan's time into the frame of the present corridor. From it the
program reads F (the wall ahead), both side walls, and the island's inner corner. The width of the next corridor is
F minus the corner's distance, measured about 1.3 m before the corner. The direction (clockwise or counter-clockwise)
is chosen at the start from the gap at the first corner and checked again at the island's end.

### One arc per corner

A corner is one constant-radius 90° arc from this corridor's lane to the next corridor's lane. The radius is as large
as fits:

- the island corner stays at least 180 mm from the body along the rear-axle arc, plus the car's measured offset toward
  the island and a term that grows with speed;
- the straight after the arc keeps room for the next arc;
- in corridors of 800 mm or less the lane runs 45 mm toward the outer wall, which allows a larger radius.

The arc starts when its predicted end is right: the steering the car already has and the servo's 85.6 °/s slew are
taken into account. A fixed lead had coupled the old lane's offset into the new one (+149 / −190 mm alternating, SIM).

### Speed plan

| Element | Value in the 14.7 s run | Source |
|---|---|---|
| Straight speed asked | up to 1.8 m/s true speed | preset `l2` |
| Arc speed | √(2.6 m/s² × R) | preset `l2` |
| Braking to the arc speed | constant 1.8 m/s² plan, 0.10 s lag, motor command 0 (PWM-low brake) until the observer is on the plan | preset `fast7`, inherited |
| Arc speed hold | the command whose duty gives the arc speed on the fitted line | open_v7 change V7-3 |
| Steering in the arc | atan(L(v) / R), L from the measured effective-wheelbase curve | open_v7 change V7-4 |
| Below the asked speed | the drive is asked for more than the target, so the motor's 0.56 s lag closes the gap 2.5 times faster | open_v7 change V7-9 |

The speed in all of these is the observer's true speed, not the drive's command (see
[Power and sensors](02-power-and-sensors.md#speed-without-an-encoder)).

### Lap-1 map and replay

Lap 1 measures the width of every corridor and every next width. Laps 2 and 3 plan every corner from that map before
the corner is in sight (radius, arc speed, braking point) and keep measuring; a measurement seen twice that disagrees
with the map wins. A corner whose next width was not measured in time is planned on 600 mm, the narrower legal width:
the car then turns a little late in a 1000 mm corridor instead of early into a 600 mm one. This replaced a stop to
measure, which cost about 2.5 s.

### Finish

After 12 corners the car brakes to stop inside the start section on the planned distance to the wall ahead. In the
14.7 s run it stopped at F = 1541 mm, inside the start-section window of 1182–1957 mm (MAT).

### Safety

The lidar shield projects every command on the true speed and the steering, and slows, steers or brakes when the
projected footprint would reach a wall. A hold that lasts backs the car off and steers its nose back onto the lane.

```mermaid
flowchart TD
    S["Start section, car still"] --> D["Direction from the corner gap"]
    D --> C["Corridor frame: F, sides, island corner"]
    C --> W{"Next width known?"}
    W -->|"yes"| A["Plan arc R, v_arc = sqrt(a R), braking point"]
    W -->|"no"| U["Plan on 600 mm"]
    A --> G["Straight at speed, brake on the plan, arc on the predicted trigger"]
    U --> G
    G --> N{"12 corners?"}
    N -->|"no"| C
    N -->|"yes"| F["Brake to stop inside the start section"]
```

## Obstacle Challenge: `obs_v17`

<p align="center">
  Top view of the practice-mat layout with six signs and the parking lot: the path of the 55.8 s obs_v17 mat run (orange, dashed) over the SIM path (blue), with a timeline of both runs
  <br><sub>From the <a href="arena/README.md">obs_v17 replay</a>. The MAT path is the car's own lidar pose, logged twice a second, not external tracking.</sub>
</p>

```mermaid
stateDiagram-v2
    [*] --> LotStart
    LotStart --> Exit: direction from the outer wall beside the car
    Exit --> Laps: last exit leg skipped, car already turned toward the corner
    Laps --> Laps: sign seats, colours, lane per sign
    Laps --> QLine: 2.2 quarter laps before the end
    QLine --> QStop: braking distance reached
    QStop --> Realign: off Q in x, y or heading
    Realign --> QStop: back 380 mm along the line, in again, creep
    QStop --> Park: on Q
    Park --> Check: exit plan driven in reverse
    Check --> [*]: all 4 corners inside = parked
```

### Pose

The car's position comes from the lidar. Every scan's wall points (pillars, limitations and clutter removed) are
fitted to the field's walls, the outer square and the island, and to the lot's limitations once the lot is known. The
fit is a damped point-to-line ICP that starts from the gyro heading and the speed observer; a point farther than 70 mm
from any wall is not used. Along a direction no wall constrains, the odometry is kept. In the 55.8 s run: 551 fits,
6 rejected, median error 5.5 mm (MAT).

### Start in the lot

The outer wall about 45 mm beside the body tells the direction: on the car's right means counter-clockwise. The wall
and the island face give the lateral position and the heading. The position along the lot cannot be seen from inside
it (the front limitation hides the wall ahead), so the program starts from the nominal position and, once out, moves
the car and the lot together by a 1-D search on the wall ahead. The limitations seen on the last lap refine the lot.

### Lot exit

The exit plan is a wiggle plus an S-curve to a point Q at least 360 mm off the wall. It is planned and driven on the
real lock of each side: 30° left (radius 237 mm) and 22° right (339 mm), on the slow 137 mm effective wheelbase, with a
28 mm margin to the limitations. Counter-clockwise it has 7 legs, clockwise 9. The last leg of the S is not driven: the
car leaves the lot already turned toward the first corner (about 62°) and the lap path takes over.

Each leg ends on a measured quantity: a turning leg on the gyro's absolute heading, a straight leg on the lidar pose in
the lot's frame. A leg runs fast, stops 22 mm short and creeps the rest; a leg that closes on a limitation nearer than
12 mm ends there. Exit legs run at 0.16 m/s, park legs at 0.11 m/s, creeps at 0.06 m/s. The program does not use short
timed pulses: the motor's 0.56 s lag turns a 30–60 ms kick into about 1 mm.

### Signs

| Step | How |
|---|---|
| Find | lidar pillar clusters, snapped to the 24 seats the rules allow (within 120 mm) |
| Colour | camera blobs paired by bearing (within 4°) at the pose the frame was taken; two votes set the colour |
| Keep | seats and colours persist over the laps |
| Exclude | anything within 270 mm of an outer wall is the lot's limitation, not a sign |
| Rule | red: pass on its right; green: pass on its left |

When a seat has a lidar pillar but no colour, the program reads it on purpose:

- **Glance.** If the sign sits just past the frame's usable edge (27°), the nose turns toward it until it is 6° inside
  the frame, for signs up to 16° past the edge, 600–1750 mm away, at most 1.5 s per sign. No glance is made across a
  sign closer than 900 mm ahead.
- **Map look.** The program projects the sign's 50 mm face into the frame where the map puts it and counts pixels in a
  strip 20–80 mm above the mat, with looser saturation and value limits (70 and 26) than the normal masks. One colour
  must fill 30 % of the window and outnumber the other three times, in two frames.

In the 55.8 s run the camera gave 104 colour votes from 115 frames, the map look 4 more, and all six signs had a colour
by the end of lap 1 (MAT).

### Path and speed

The path planner puts a lane beside each sign on the side the colour demands, at least 85 mm from the sign to the body
and 45 mm from the walls, and moves at most 170 mm between neighbouring signs. Corner radii are chosen from
300–720 mm and checked against the known signs, the island and the lot. Pure pursuit from the rear axle follows it,
with a look-ahead of max(260 mm, 0.45 s × speed) and the effective wheelbase at the present speed. A guard sweeps the
car's footprint along candidate arcs and keeps 30 mm clear.

| Setting | Value |
|---|---|
| Lap 1 speed (signs not yet read) | 0.50 m/s |
| Laps 2 and 3 (map known) | 0.80 m/s |
| Near a sign without a colour | 0.30 m/s |
| Planned lateral acceleration | 1.1 m/s² |
| Lock kept in reserve by the speed profile | 6° |

Two signs 500 mm apart that ask for opposite sides need a lane shift of 330–530 mm. With a 339 mm right-turn radius
the car cannot always make that shift; after two shield holds beside such a pair the planner relaxes it from the next
straight on.

### Parallel park

1. **Q's line.** 2.2 quarter laps before the end, the start straight's lane moves onto the line through Q, the end of
   the exit plan. A sign within 900 mm before Q is passed on that line.
2. **Stop at Q.** The stop fires at the real braking distance, v² / (2 × 2.4 m/s²) + v × 0.08 s, from the lidar speed.
3. **Realign.** If the car is off Q by more than 8 mm along the line, 12 mm across it or 2.5° in heading, it backs
   380 mm along the line and comes in again, then creeps along the line onto Q at 0.06 m/s. At most 3 tries.
4. **Park.** The exit plan is driven in reverse, leg by leg, with the same measured leg ends.
5. **Check.** The final pose is checked against the lot; the run ends "parked" only when all four corners of the car
   are inside.

A three-move park does not fit: our planner's minimum in this lot is 5 legs with 30° on both sides and a 12 mm margin,
7 legs at a 20 mm margin, and 9 with the real 22° right lock. With 30° left and 22° right the counter-clockwise plan
has 7.

### Battery hold

For the whole run the drive's battery scaling is held at its 7.0 V value, so the park legs move the same distance on
any pack. Restored at the end of the run.

### The 55.8 s run, event by event

Run `20261001-222840.106-obs_v17`, counter-clockwise, pack 8.25 V. Times on the program's clock.

| Time (s) | Event |
|---|---|
| 8.1 | lot exit done |
| 20.3 | lap 1 done; seats 1.0 green, 1.2 red, 2.0 green, 2.2 red, 3.0 green, 3.2 green |
| 30.2 | lap 2 done |
| 40.0 | lap 3 done |
| 41.0 | first stop at Q: 59 mm off along the line, 4 mm across, 3.1° |
| 44.1, 44.7 | realigns: 35 mm / 9 mm / 1.6°, then 33 mm / 6 mm / 2.4° |
| 45.2 | park starts |
| 55.8 | parked: all 4 corners inside, final heading −0.7° |

Shield interventions: 16 slow-downs, 5 steering corrections, 1 brake. Highest horizontal acceleration 0.42 g.

## Edge cases the code handles

| Case | Handling |
|---|---|
| Next corridor width not measured in time (Open) | plan on 600 mm |
| Measurement disagrees with the lap-1 map (Open) | a measurement seen twice wins |
| Sign the camera cannot see in time (Obstacle) | glance and map look |
| Two signs that ask opposite sides close together | try; after two holds, relax the pair |
| Limitation read as a red sign | outer-wall band filter |
| Car off Q | realign along the line, then creep |
| Car held by the shield | back off 150 mm, nose onto the lane; at most 6 holds |
| Pose unconstrained along a corridor | keep the odometry along it |
| RRC Lite stream stops / servo stops following | reopen the board (see [failure modes](02-power-and-sensors.md#failure-modes-and-how-the-code-handles-them)) |
| Low or full pack | battery hold at 7.0 V (Obstacle) |

## Constants and where they come from

| Constant | Value | Program | Source |
|---|---|---|---|
| Speed line | 5.276 m/s per duty, intercept 0.1012 | both | FIT, 1599 samples |
| Motor lag | 0.56 s | both | FIT |
| PWM-low brake | 2.08 m/s² (model), 1.8 m/s² (Open plan), 2.4 m/s² (Q stop) | both | FIT; 2.4 fitted on the Q overshoot of run `20261001-203331.245-obs_v13` |
| Steering trim | −4° | both | MAT, 2026-10-01 |
| Lock | 30° left, 22° right | both | MAT |
| Effective wheelbase | 137 mm at 0.2 m/s to 281 mm at 1.7 m/s | both | FIT, 2694 samples |
| Servo slew | 85.6 °/s | both | MAT |
| Island clearance | 180 mm | Open | SIM: planned 130–150 mm became 63–98 mm executed at 1.1–1.52 m/s |
| Planned lateral acceleration | 2.6 m/s² | Open | mat ladder: 2.2 (16.0 s), 2.6 (14.7 s) |
| Unmeasured corridor | 600 mm | Open | the rules' narrow width |
| Lap speeds | 0.50 / 0.80 m/s | Obstacle | mat ladder |
| Lock reserve | 6° | Obstacle | MAT: 1.5° let lap 2 enter corner 2 at 0.69 m/s and pass the next green on the wrong side; 6° gave every sign right in 2 mat runs |
| Exit and park margin | 28 mm | Obstacle | planner; the first full park's nearest lot edge was 12.7 mm |
| Q off the wall | at least 360 mm | Obstacle | at the planner's own minimum, 303 mm, the body passed the limitations 47 mm off and the shield held it |
| Q tolerance | 8 mm along, 12 mm across, 2.5° | Obstacle | park accuracy |
| Battery hold | 7.0 V | Obstacle | MAT and FIT (see [decisions](04-engineering-decisions.md#battery-compensation-that-over-corrected)) |
| Outer-wall band | 270 mm | Obstacle | limitations stand 200 mm out, signs 400 or 600 mm |
| Camera field of view | ±29.3°, usable edge 27° | Obstacle | MAT intrinsics |

## How we tune

- One change per mat run, with the same start pose and a known pack voltage.
- Every program version is a new file with one named change and the mechanism it fixes written in its header; a
  version that is proven on the mat is frozen (its SHA-256 recorded) and never edited again.
- Changes are tried in the calibrated simulator first, then on the mat. A SIM result never decides alone.
- After each run the log is pulled and checked: the observer error, the arc entry speeds, the lane entry offsets, the
  finish position, the Q stops, the park result, and any board or steering fault.

<sub>[Back to the README](../README.md)</sub>

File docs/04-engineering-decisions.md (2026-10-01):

# Systems thinking and engineering decisions

Appendix C criterion 4. The constraints we worked under, the decisions we made and the data behind them, what we
learned on the mat, how the programs evolved, and the risks that remain.

Tags: **MAT** measured on the car; **FIT** fitted from mat run logs; **SIM** simulator. A run ID names the log file of
that run. Pack voltages are the first reading in each log.

## Summary

- We changed platform on 2026-09-23 and had three weeks to the event. That, and the rule that the car may only use
  parts the team already owns, shaped most decisions: no encoder, no new electronics.
- The car's position comes from the lidar, so the lidar had to see the walls; its speed comes from a fitted motor
  model, so the model had to match the mat.
- Four measured lessons changed the programs most: the steering trim and the unequal lock, the battery compensation,
  the stop at Q, and the camera's field of view. Each is below with its numbers and run IDs.

## Constraints

| Constraint | Effect on the design |
|---|---|
| Rules 11.3, 11.5, 11.13: one driving axle, no independently connected drive motors | the kit's two-motor rear axle could not be used; WLtoys chassis with one motor and differentials |
| Rule 11.10: no radios during a round | race mode blocks every radio before the program starts |
| Rules 9.10, 9.11: one power switch, one start button | one latching switch, one push button on GPIO17 |
| Only parts the team owns | no wheel encoder; the motor runs on the MD13S we already had |
| Walls 100 mm high | lidar scan plane at 50 mm |
| Corridors 600 or 1000 mm, drawn at random | the Open program measures each next width and plans unknown ones on 600 mm |
| Parking lot 1.5 × the car's length | the park is planned on the car's true footprint and the real lock of each side |
| Three weeks from platform change to event | one change per mat run, each version a new file, a simulator calibrated to the mat |

## How the subsystems depend on each other

| From | To | What can go wrong |
|---|---|---|
| Lidar plane height | pose, sign positions, shield | a plane above the walls sees the room, not the field |
| Steering trim | every arc, every park leg | an untrimmed car turns less on one side |
| Motor model | speed observer, braking point, park legs | a model that ignores the pack's effect moves the park by tens of millimetres |
| Camera pitch and field of view | sign colour, map look | a sign outside the frame is never read; a pitch error moves the map projection |
| Gyro integration | pose between scans | a dropped sample turns into a heading error in a corner |
| Board link (RRC Lite) | servo and IMU | a stalled stream leaves the wheels at their last angle |

## Decision log

| We chose | Instead of | Because |
|---|---|---|
| WLtoys chassis, one motor, differentials | the kit's chassis | the kit drives each rear wheel with its own motor, which rules 11.5 and 11.13 do not allow |
| MD13S driven from the Pi's GPIO | the RRC Lite's motor ports | those ports run a speed loop on an encoder; without one the board drives the motor to 100 % and a stop does not stop it |
| Software PWM at 490 Hz | the Pi 5's hardware PWM | the hardware PWM channel returned an error on GPIO12 |
| Lidar scan plane at 50 mm | the kit's mount | on the kit's mount the lidar read 2.5–4.3 m past the field and missed a pillar 25 cm ahead (MAT, 2026-09-22) |
| Sign colour by bearing to the lidar pillar | range from the camera | bearing pairing does not depend on the pitch; the depth stream over-read a pillar at 1.25 m as 1.43 m |
| Fitted speed line 5.276 × (duty − 0.1012) | the profile's first line (4.49, 0.1187) | rms error 0.075 m/s against 0.271 m/s on the same 1599 lidar speeds (FIT) |
| A speed observer for the Open braking plan | the drive's own estimate | the drive's estimate read 1.24–1.53 times under the car at 7.1 V and the lidar speed is stale in arcs; the pre-corner brake barely fired |
| One constant-radius arc per corner | full lock from the lane centre | full-lock corners run at 0.35–0.5 m/s |
| Effective wheelbase taken at the present speed | one value, 210 mm | with one value every arc at 1.3–1.5 m/s came out about 30 % too wide (SIM) |
| Plan an unmeasured corridor on 600 mm | stop and measure | the stop cost about 2.5 s; a late turn into 1000 mm is safe, an early one into 600 mm is not |
| Steering lock per side, 30° left and 22° right | 22° both ways | corners asked 34–44° while the program capped 22°, and the car blocked (see below) |
| Battery hold at 7.0 V in the Obstacle program | the drive's battery compensation | the compensation over-corrected this car (see below) |
| Stop at Q on the braking distance | a fixed 50 mm lead | the car came off the last corner at 0.8–0.9 m/s and stopped 159 mm past Q (see below) |
| A new file for each program version, proven ones frozen by SHA-256 | editing the program in place | every mat result stays reproducible; a regression can be compared with the exact file that worked |

## Lessons measured on the mat

### Steering trim and the unequal lock

**Symptom.** `open_v2_25s` drove 25.2 s counter-clockwise (run `20260930-235056.569-open_fast_v2`, 7.01 V) but
blocked after one corner when run clockwise (11.6 s). Clockwise runs lost about half of each right turn;
counter-clockwise runs hid the problem because left turns still reached their radius.

**Measurement.** On 2026-10-01 the wheels pointed straight ahead at a servo command of −4°, all day (MAT). The fit over
the mat logs found the same bias: +4.05° in corners at 0.6–1.2 m/s (FIT, 2694 samples).

**Change.** `open_v4` adds −4° to every steering command. Result: 12 of 12 corners driven without stopping in both
directions: clockwise 23.3 s (run `20261001-001646.802-open_v4`, 6.40 V) and 26.3 s
(`20261001-005127.677-open_v4`, 7.28 V), counter-clockwise 28.6 s (`20261001-005755.103-open_v4`, 7.18 V).

**Second effect: the lock.** The servo is limited to ±26°. On top of the −4° trim that gives 30° at the wheels to the
left and 22° to the right (MAT). The first Obstacle programs capped the steering at 22° both ways. At the corners every
stop asked for 34–44°, and `obs_v2` blocked twice (runs `20261001-164201.458-obs_v2` at 0.33 laps and
`20261001-164524.976-obs_v2` at 0.60 laps). `obs_v3` gave each side its own cap and smaller corner radii (300 and
340 mm) and made the first full Obstacle run with a park: 69.4 s, all 4 corners in, nearest lot edge 12.7 mm (run
`20261001-165354.604-obs_v3`, 7.45 V). `obs_v12` then planned the lot exit and the park on the per-side lock too: 7 legs
instead of 9 each way counter-clockwise, 73.3 s to 68.2 s (run `20261001-202156.652-obs_v12`, 7.00 V).

**Checked again.** `BEST_OPEN_14s` with the trim at −4.6° drove 15.0 s against 14.7 s at −4° (runs
`20261001-161351.882-open_v7` and `20261001-161301.412-open_v7`), so −4° stayed.

### Battery compensation that over-corrected

**Mechanism.** The drive code multiplies the duty by v_ref / V_pack with v_ref = 8.0 V, assuming the motor slows on a
low pack. The fit over 20 mat runs found that this car's speed per duty does not fall with the pack (exponent 0.0,
FIT); with the compensation a 6.4 V run went faster than a 7.3 V run for the same command. At 6.1 V the compensation
multiplies the duty by 1.31; in SIM that made the true speed 38 % higher.

**Symptom on the mat.** `obs_v16` (run `20261001-204736.982-obs_v16`, 6.33 V at the start) drove fast laps (lap 3 done at 40.0 s) and stopped 34 mm from Q, but the park legs and the creep onto Q overshot by 30–150 mm
and the park ended with 1 of 4 corners in the lot.

**At the other end.** On a full pack the compensation lowers the duty. `obs_v7` at 8.09 V (run
`20261001-190131.030-obs_v7`) lost its along-track position in lap 2 and blocked at 1.22 laps; the same code at
7.25 V drove all three laps.

**Change.** `obs_v17` holds the compensation at its 7.0 V value for the whole run, whatever the pack, and restores it at
the end. Result at 8.25 V: 55.8 s, all signs on the correct side, full park (run `20261001-222840.106-obs_v17`). The
Open program is not affected: it plans on the observer's true speed.

### The stop at Q: short, then long

The park starts from Q, the point where the lot exit ended. The car must stop there within 8 mm along the line, 12 mm
across and 2.5° in heading.

**Short.** In the 8 runs from `obs_v3` to `obs_v7` that tried to park, every realign after the first stop ended 35–76 mm
short of Q (15 realigns, MAT), and 4 of the 8 parks were full. The forward drive along the line stops 0.25 s × v before
the target (about 50 mm at 0.2 m/s) to leave room for coasting, but the PWM-low brake stops the car dead, so it stayed
there. The creep that should close the gap only ran when the lateral and heading errors were already in tolerance, and
they never were. `obs_v11` creeps onto Q after every realign: the realign errors fell to 15 and 18 mm and the park was
full (run `20261001-201055.680-obs_v11`, 73.3 s, 7.10 V).

**Off the line.** Until `obs_v12` the first stop at Q came 39–51° off the line's heading (63° in `obs_v10`, whose lot model was wrong), because the lap path already
bends into the next corner there; the realigns took about 10 s. `obs_v13` rides Q's line straight for the final
approach: 57.6 s with a full park (run `20261001-203331.245-obs_v13`, 6.80 V).

**Long.** In that run the car came off the last corner at 0.8–0.9 m/s and stopped 159 mm past Q with the fixed 50 mm
lead, which cost a 4.5 s realign. Fitting the stop gave 2.4 m/s². `obs_v16` fires the stop at
v² / (2 × 2.4) + v × 0.08 s: the first stop was 34 mm off (run `20261001-204736.982-obs_v16`). In the 55.8 s run the
first stop was 59 mm off and two realigns brought it in; the park started 5.1 s after lap 3.

**Rejected.** A longer look-ahead on Q's line (`obs_v18`, team note; that run's log was not kept) reached Q 25 mm
aside; each realign left 16 mm and then 14 mm across, over the 12 mm tolerance, and the run took 62.4 s. The lateral
tolerance is the one that binds.

### The camera could not see the sign

**Symptom.** In run `20261001-174628.799-obs_v5` the green sign after corner 2 (seat 2.0) was passed on the wrong side in
all three laps. The lidar had that seat in every lap; the camera never gave it one colour vote (the lap maps list five
signs). The other five signs were read at the usual 1.2–1.7 m, so the pitch was not the cause, and the simulator's
rendered camera failed the same way (seed 1), so the light was not the cause either.

**Mechanism.** On the straight before corner 2 the car aims to the right to pass the red sign 1.2 on its right. The
green sign then stays 30–60° off the camera axis, outside the ±29.3° field of view, and enters the frame only about
250 mm away, beside the car. With no colour the car took the default lane.

**Change.** `obs_v7` reads an unread sign on purpose: the nose turns toward it when it sits just past the frame edge,
and the program counts pixels where the map projects the sign. In run `20261001-195904.068-obs_v7` the car glanced at
that seat at a bearing of 33.2° and 1560 mm, all six signs had a colour by the end of lap 1, and all 18 passes were on
the correct side.

**What we kept from it.** When a sign is passed on the wrong side, first check whether its seat got any colour vote. If
not, it is a field-of-view problem, not a path or colour-threshold problem.

### Camera pitch

The model's wedge is 16°; on the car we measured 19.61° (MAT, 2026-10-01). In SIM, 1° of pitch error moved the pose of
our camera-based localisation by a median 116 mm, and the kit's camera mount moved about 10° in one day before we had
the printed tower. The tower and the keyed wedge hold the camera; the pitch check before every session measures it.
The Obstacle program pairs colours by bearing, so the pitch only affects the map look's projection.

## Version history

The Open Challenge, on the mat:

| Program | Change | Result | Run |
|---|---|---|---|
| `open_v2_57s`, `open_v2_46s`, `open_v2_27s` | lidar laps; then the racing line | 57.5 s, 45.9 s, 27.3 s | frozen file notes |
| `open_v2_25s` | faster arcs (planned 1.5 m/s²) | 25.2 s CCW, 7.01 V; blocked clockwise | `20260930-235056.569-open_fast_v2` |
| `open_v4` | steering trim −4°, arcs on a 210 mm effective wheelbase | 23.3 s CW, 6.40 V; 28.6 s CCW, 7.18 V | `20261001-001646.802-open_v4`, `20261001-005755.103-open_v4` |
| `open_v5_18s` | larger arcs, duty up to 0.5, shield on the measured brake | 18.8 s CW, 7.10 V | `20261001-010507.423-open_v5` |
| `open_v6` (`BEST_OPEN`) | brake and lead on the lidar speed | 18.7 s CCW, 7.04 V | `20261001-011031.386-open_v6` |
| `open_v7`, preset `l1` | speed observer, constant-deceleration brake, held arc speed, wheelbase curve, unknown corridor on 600 mm | 16.0 s CCW, 8.06 V | `20261001-161218.085-open_v7` |
| **`BEST_OPEN_14s`** (`open_v7`, preset `l2`) | planned lateral acceleration 2.6 m/s², straights to 1.8 m/s | **14.7 s CCW, 8.05 V** | `20261001-161301.412-open_v7` |
| `open_v7`, preset `fast7` | 3.0 m/s², straights to 2.0 m/s | 16.3 s CCW, 8.06 V: the shield braked 18 times near the walls | `20261001-161418.641-open_v7` |

The Obstacle Challenge, on the mat, all counter-clockwise, start in the lot:

| Program | Change | Result | Run |
|---|---|---|---|
| `obs_v1` | first program: lidar pose, sign seats, lane per sign, lot exit and park | blocked at 0.1 laps: a 0.14 m/s creep never moved the car, and the lot read as red signs | `20261001-163348.547-obs_v1` |
| `obs_v2` | outer-wall band, creep at 0.20 m/s | blocked at 0.33 and 0.60 laps: 22° cap | `20261001-164201.458-obs_v2`, `20261001-164524.976-obs_v2` |
| `obs_v3` | lock per side, corner radii 300 and 340 mm | **first full park: 69.4 s**, 7.45 V; repeat 71.2 s, 7.36 V | `20261001-165354.604-obs_v3`, `20261001-165946.260-obs_v3` |
| `obs_v4` | faster exit legs (0.16 m/s) | 67.6 s parked, 7.17 V; two more runs ended with 3 and 1 corners in the lot | `20261001-171309.381-obs_v4` |
| `obs_v5` | 6° of lock kept in reserve | 72.6 s parked, 6.99 V; repeat: green 2.0 wrong side, 3 corners in | `20261001-173009.016-obs_v5`, `20261001-174628.799-obs_v5` |
| `obs_v7` | glance and map look | all signs read; Q stop short, 1 corner in | `20261001-195904.068-obs_v7` |
| `obs_v10` | lot refined on every lap | 0 corners in: one limitation face is ambiguous between two lot positions 340 mm apart | `20261001-200413.723-obs_v10` |
| `obs_v11` | creep onto Q after each realign | 73.3 s parked, 7.10 V | `20261001-201055.680-obs_v11` |
| `obs_v12` | exit and park on the lock of each side (7 legs) | 68.2 s parked, 7.00 V | `20261001-202156.652-obs_v12` |
| `obs_v13` | leave the lot turned; ride Q's line | 57.6 s parked, 6.80 V | `20261001-203331.245-obs_v13` |
| `obs_v16` | stop at Q on the braking distance | Q within 34 mm; 1 corner in at 6.33 V | `20261001-204736.982-obs_v16` |
| **`obs_v17`** | battery hold at 7.0 V | **55.8 s parked, 8.25 V** | `20261001-222840.106-obs_v17` |

Of the 18 Obstacle runs on 2026-10-01, 8 ended with a full park. The others are the development failures in the table.

## What did not work

| Attempt | Result | Why |
|---|---|---|
| Faster Open preset `fast7` on the mat | 16.3 s, slower than `l2` | the shield braked 18 times near the walls |
| Trim −4.6° on `BEST_OPEN_14s` | 15.0 s | −4° was already right |
| Lot refined on every lap (`obs_v10`) | 0 corners in | a single limitation face fits two lot positions 340 mm apart |
| Quicker park legs and a shorter back-up (SIM) | lost the park in SIM | about half of the exit time is servo swings (0.66 s per full reversal at 85.6 °/s); a faster servo would gain more than faster legs |
| Longer look-ahead to Q (`obs_v18`) | 62.4 s | the lateral error converged too slowly |
| A three-move park | not possible in this lot | the planner's minimum is 5 legs at 30° both sides |

## Risks and mitigations

| Risk | Mitigation |
|---|---|
| Both main programs have been run on the mat counter-clockwise only | SIM both ways; on the mat the Open fallbacks cover both directions, `BEST_OPEN` 18.7 s CCW and `open_v5_18s` 18.8 s CW (the same settings without `v_meas_max`); clockwise mat runs of the main programs before the event |
| Our mat had only 1000 mm corridors | SIM on random 600 / 1000 corridors; unknown widths are planned on 600 mm |
| Camera pitch changes after a knock | keyed wedge; pitch check before each session |
| Venue light changes the colours | hue check on arrival; colour by bearing; map look with looser limits |
| Lot length set by the judges differs from our model | the lot's position is refined from the limitations seen on the last lap |
| Servo or board link stalls | watchdogs reopen the board; standing steering limited to 12° |
| Pack voltage | battery hold in the Obstacle program; runs started at 7.4 V or more |
| Race-mode start path | rehearse the full race-mode start on the practice mat before the event |
| Mass and height only from CAD | weigh and measure the car before the event; both have a large margin to rules 11.1 and 11.2 |

## Next steps

1. Clockwise mat runs of `BEST_OPEN_14s` and `obs_v17`.
2. Runs with 600 mm corridors on the practice mat.
3. Full race-mode rehearsal: radios off, start button only.
4. Weigh the car and measure its height.
5. Re-centre the servo horn for a more equal lock, then re-measure trim and lock before any program uses it.

<sub>[Back to the README](../README.md)</sub>

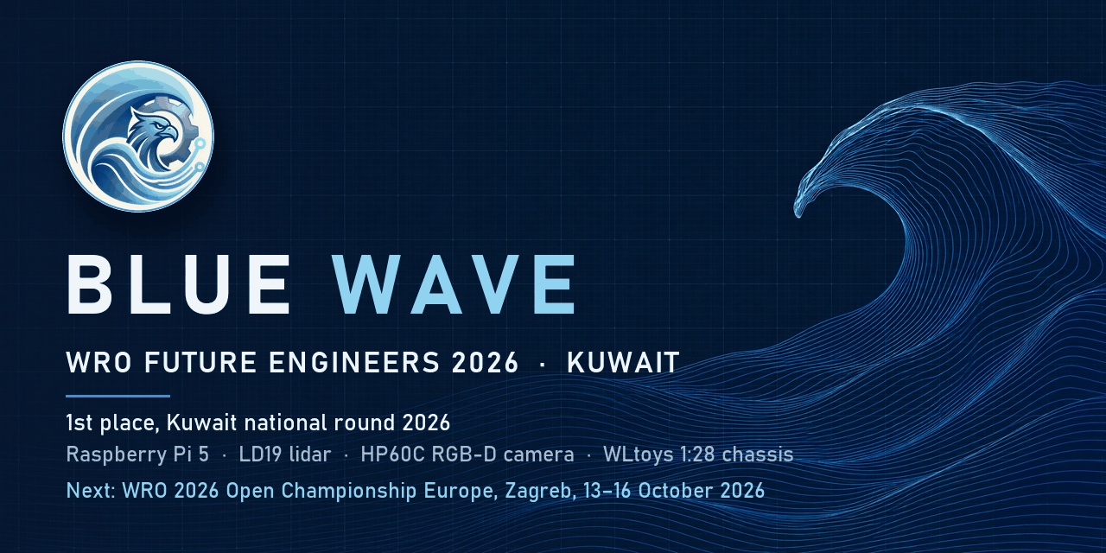
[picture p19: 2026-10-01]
docs/images/social_preview.png

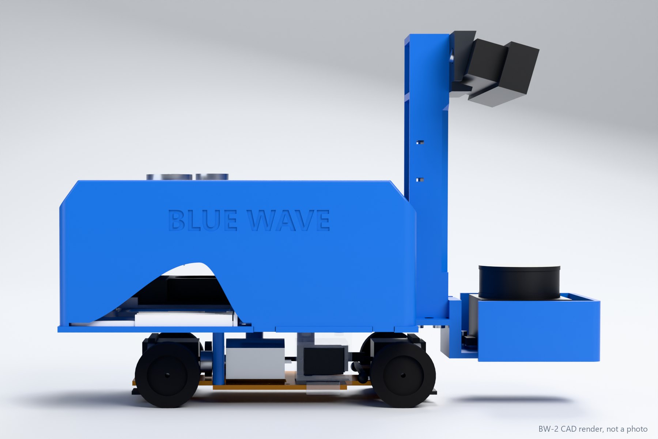
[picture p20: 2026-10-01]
docs/images/bw2_render_side.jpg

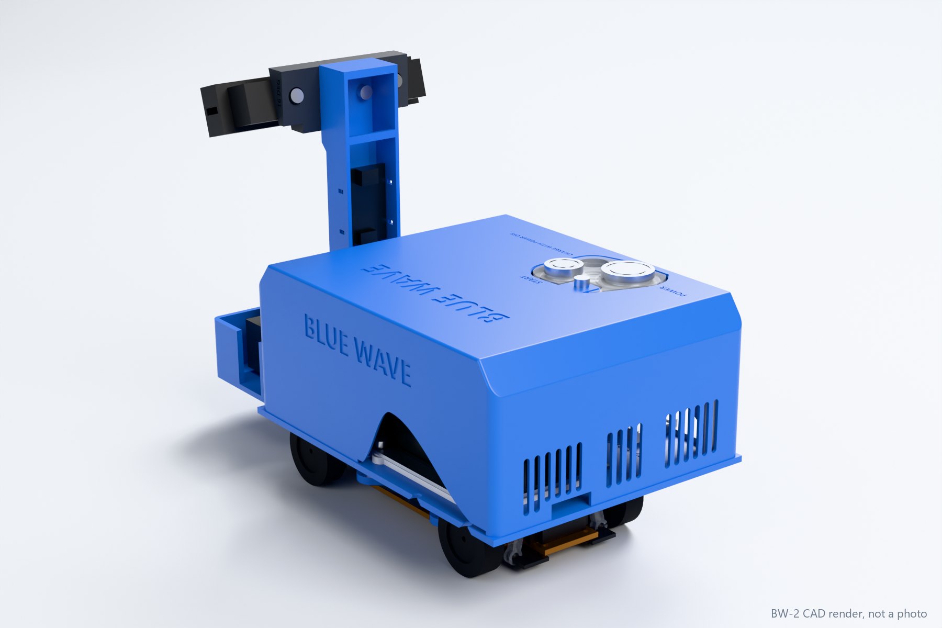
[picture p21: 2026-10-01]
docs/images/bw2_render_rear34.jpg

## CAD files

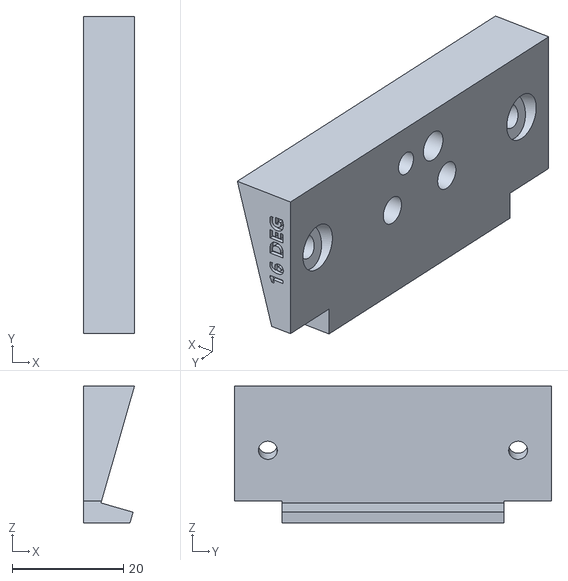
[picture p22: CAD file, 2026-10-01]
Models/07_cam_wedge_16deg_darkgrey.stl
9.17 x 57.0 x 24.6

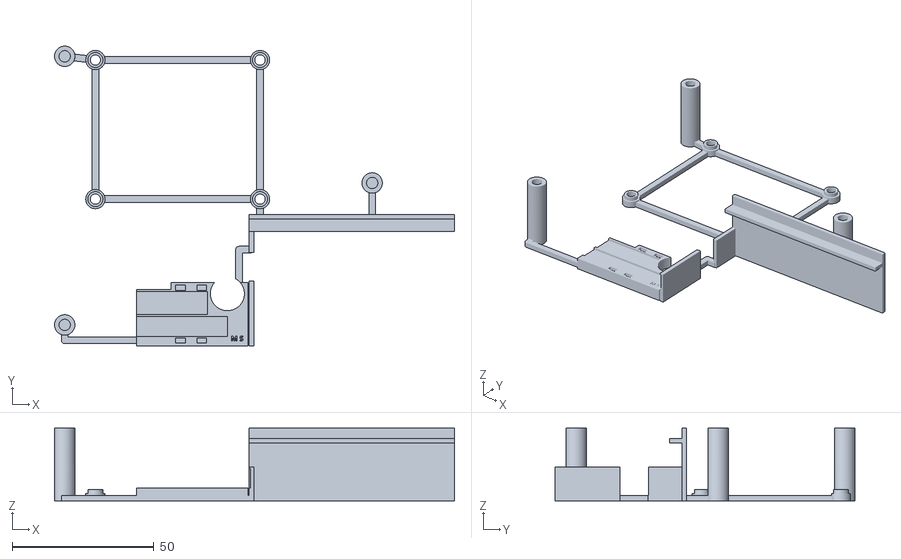
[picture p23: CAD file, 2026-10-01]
Models/02_L1_frame_battery_tray_darkgrey.stl
140.9 x 105.6 x 25.7

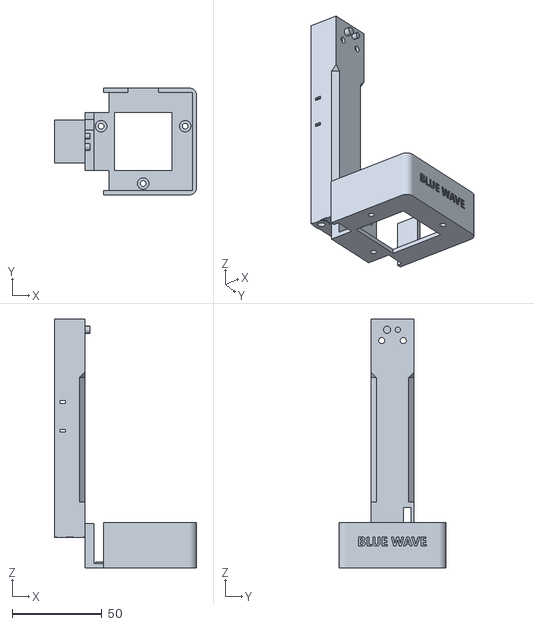
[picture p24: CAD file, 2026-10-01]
Models/04_tower_blue.stl
79.2 x 59.5 x 138.6

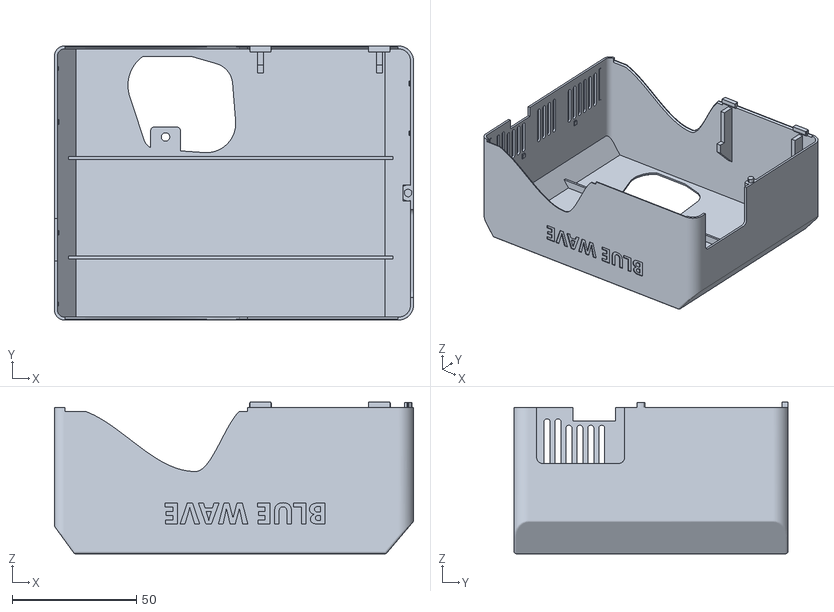
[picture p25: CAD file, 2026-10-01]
Models/05_shell_blue.stl
144.4 x 110.2 x 61.0

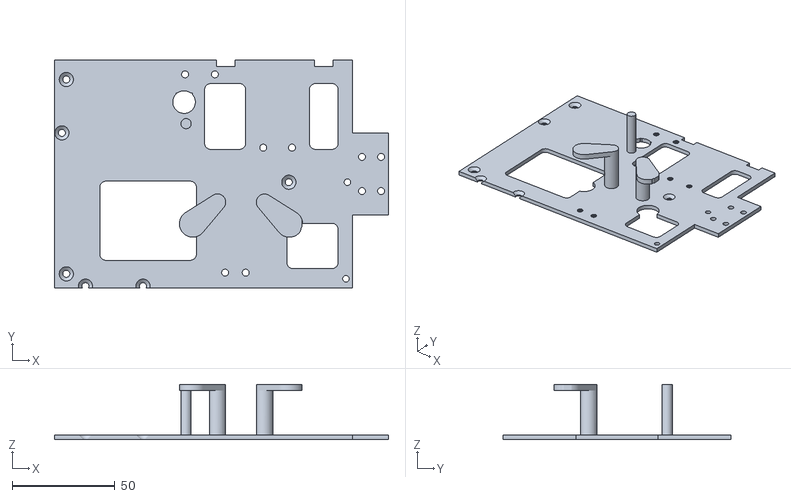
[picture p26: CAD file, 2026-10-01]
Models/01_D1_deck_darkgrey.stl
162.6 x 111.0 x 27.0

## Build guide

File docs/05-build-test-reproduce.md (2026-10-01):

# Build, test and reproduce

Appendix C criterion 5. What to buy and print, how to set up the software, how we test, every mat result with its
run ID, and how to repeat each number on these pages.

Tags: **MAT** measured on the car; **FIT** fitted from mat run logs; **SIM** simulator; **CAD** body model; **EST**
estimate or listing value.

## Bill of materials

| Part | Model | Role | Mass |
|---|---|---|---|
| Chassis | WLtoys 1:28, model 284131, four-wheel drive, with its stock tyres, 130-size motor, micro servo, propshaft and differentials | drive and steering | 125 g with motor and servo (EST) |
| Computer | Raspberry Pi 5 with the Active Cooler | perception, planning, control | 66 g (EST) |
| Controller board | Hiwonder RRC Lite (STM32F407), stock firmware | servo, IMU, buzzer, keys; powers the Pi | 32 g (vendor) |
| Motor driver | Cytron MD13S (6–30 V, 13 A) | PWM and direction drive of the motor | 20 g |
| Lidar | LDROBOT LD19 with its USB serial adapter | 360° range scan | 47 g without cable (vendor) |
| Camera | Angstrong HP60C RGB-D, USB-C | colour of signs and limitations | 56.2 g (EST) |
| Battery | Hiwonder 7.4 V 2200 mAh 10C (2 × 18650, protection board), DC 5.5 × 2.5 mm charge lead, 8.4 V 2 A charger | power | 105 g (EST) |
| Power switch | 16 mm latching push switch | the one power switch | 12 g (EST) |
| Start button | 12 mm momentary push button | the one start button | 5 g (EST) |
| Cables | USB-C to USB-C rated 5 A (board to Pi); USB cables for lidar and camera; Grove cable to the MD13S; jumper for the body strap | | |
| Printed body | 5 PETG parts, see [Models](../Models/README.md) | body, lidar bay, camera mount | 157 g of PETG (EST) |

## Printed parts

Five parts, PETG, 0.4 mm nozzle; settings and files in [Models](../Models/README.md). Print the tower with its brim
and the support enforcer under its foot; parts 02, 05 and 07 need no supports. Print time for parts 02, 04, 05 and 07 is
about 353 min (EST, slicer).

## Wiring

Pin table and schematic: [Schemes](../Schemes/README.md). The short version:

1. Pack positive → power switch → one splice to the RRC Lite power input and the MD13S V+. Pack negative → one splice
   to both.
2. RRC Lite 5 V USB-C output → Pi 5 USB-C, with a 5 A cable.
3. Pi GPIO12 (pin 32) → MD13S PWM, GPIO16 (pin 36) → MD13S DIR, pin 34 → MD13S signal ground.
4. Start button between GPIO17 (pin 11) and GND (pin 9). Body strap between GPIO5 (pin 29) and GND (pin 30).
5. Steering servo on RRC Lite PWM port 3, with the port's supply jumper at 5 V (measure 4.8–5.2 V before plugging the
   servo).
6. RRC Lite, LD19 and HP60C to the Pi's USB ports.

## Software set-up

Commands run on the laptop from `src/`, in Git Bash or cmd; `py -3` is the Windows Python launcher (`python3`
elsewhere). Every command is described in [src/README.md](../src/README.md#running-on-the-robot).

### Raspberry Pi 5, once

1. On a fresh Raspberry Pi OS Lite (64-bit) card, run `os/setup_bluewave_os.sh`: it installs `python3-numpy`,
   `python3-opencv`, `python3-serial` and `python3-lgpio` from apt, the udev rule, and the development and race
   services. On Hiwonder's stock card, run `os/install_on_stock.sh` instead; it keeps Hiwonder's container, which holds
   the HP60C driver our code reads the colour stream from.
2. The RRC Lite keeps Hiwonder's firmware. Nothing is compiled or flashed: the programs are Python and load at the start
   of a run.

### Each session

1. `py -3 tools/bw.py deploy` copies `bluewave/`, `programs/`, `race/` and `profiles/` to the car.
2. `py -3 tools/bw.py body wltoys_bw2` applies the car's calibration file and checks the body strap.
3. With the car still: `py -3 tools/bw.py preflight pitch` with one sign 500 mm ahead of the bumper, then
   `py -3 tools/bw.py preflight` until every row says GO.
4. Development runs: `py -3 tools/bw.py run BEST_OPEN_14s --wait-button` or `py -3 tools/bw.py run obs_v17 --wait-button`,
   then `py -3 tools/bw.py pull RUN_ID` and `py -3 tools/bw.py analyze latest`.
5. After any change to the car, repeat the calibrations in [Power and sensors](02-power-and-sensors.md#calibration)
   and write the new numbers into `profiles/wltoys_bw2.json`.

### Race mode

1. Choose the programs and the round:
   `py -3 tools/bw.py apply race.program= race.programs.open=BEST_OPEN_14s race.programs.obstacle=obs_v17 race.challenge=open`
   (`race.challenge=obstacle` for the Obstacle round).
2. `py -3 tools/bw.py mode race`, then switch the car off.
3. Place the car and switch on. At boot `os/bluewave-mode.sh` runs `rfkill block all` and starts `race/race_main.py`,
   which loads the program, computes what it can before the car moves, and beeps twice (READY). Nothing moves until the
   start button is pressed and released.
4. The run is written to `runs/<time>-race-<program>.jsonl` on the car. A long press of the board's second key returns
   to development mode (radios on).

### Laptop tools

| Command (from `src/`) | What it does |
|---|---|
| `py -3 -m pip install -r requirements.txt` | the simulator's packages (numpy, OpenCV, SciPy for the plant fit) |
| `py -3 tools/bw.py status` | pack voltage and board state |
| `py -3 tools/bw.py stop` | stops the car |
| `py -3 tools/sim_run.py <program> --profile wltoys_bw2 --mat1001 ...` | the simulator with the mat-fitted plant |
| `py -3 tools/fit_plant.py --bias-from corners` | refits the plant from run logs |

## Bench check before a round

| Step | Pass when |
|---|---|
| Pack voltage, car still | 7.4 V or more |
| Gyro bias, car still | measured and stored for the session |
| Camera pitch: one sign centred, its near face 500 mm from the front bumper, car still | GO |
| Lidar: scan direction and offset match the calibration | no halt at program start |
| Colours under the venue light | red, green and magenta limitations each found on a test frame |
| Start position | in the start section (Open) or in the lot parallel to the wall (Obstacle) |
| Race mode | two beeps, then still until the start button |

The [test sheet](test-sheet.md) has one row per round.

## How we test

| Level | Tool | What it gives |
|---|---|---|
| Component tests on the car | duty sweep, coast, turn radius, servo sweep, camera pitch, lidar tilt, field check, still check | the calibration numbers in `profiles/wltoys_bw2.json` |
| Unit tests | development test suite, run on 2026-10-01: test_units 23 of 23, test_body 19 of 19, test_fast_drive 11 of 11, test_wltoys 29 of 29 | the code paths without the car |
| Calibrated simulator | `tools/sim_run.py --mat1001`: the plant fitted to 20 mat run logs of 2026-09-30 and 2026-10-01, a rendered camera, the field with chosen corridors and signs | program changes compared before a mat run |
| Simulation queue | at most 3 real-time simulations at once, started only below 80 % CPU; each result stamped TRUSTED or SUSPECT | results that are not distorted by a loaded machine |
| Mat runs | one change per run, same start pose, known pack; stop after two similar failures or a pack under 7.4 V; about 60 s between runs | the results below |
| After each run | the run log; a crash map (where on the field and in which program state an incident happened); the IMU black box (contact or jolt) | what to change next |

The simulator had to pass a gate before we used it: it must reproduce mat results it was not fitted to choose. It
reproduced `open_v2_25s` blocking clockwise after one corner and `open_v4` and `BEST_OPEN` finishing clean. The old,
unfitted plant had passed `open_v2_25s` clockwise, which the mat did not.

## Results on the mat

Practice mat, all corridors 1000 mm, 2026-09-30 and 2026-10-01. Times are the program's own clock. Pack = first
voltage in the log.

### Open Challenge (3 laps, 12 of 12 corners, stop inside the start section in every row)

| Program | Run ID | Direction | Time | Pack |
|---|---|---|---|---|
| **`BEST_OPEN_14s`** (`open_v7`, preset `l2`) | `20261001-161301.412-open_v7` | CCW | **14.7 s** | 8.05 V |
| `open_v7` `l2`, trim −4.6° | `20261001-161351.882-open_v7` | CCW | 15.0 s | 8.05 V |
| `open_v7` `l1` | `20261001-161218.085-open_v7` | CCW | 16.0 s | 8.06 V |
| `open_v7` `fast7` | `20261001-161418.641-open_v7` | CCW | 16.3 s | 8.06 V |
| `open_v6` (`BEST_OPEN`) | `20261001-011031.386-open_v6` | CCW | 18.7 s | 7.04 V |
| `open_v5_18s` | `20261001-010507.423-open_v5` | CW | 18.8 s | 7.10 V |
| `open_v4` | `20261001-001646.802-open_v4` | CW | 23.3 s | 6.40 V |
| `open_v4` | `20261001-005127.677-open_v4` | CW | 26.3 s | 7.28 V |
| `open_v4` | `20261001-005755.103-open_v4` | CCW | 28.6 s | 7.18 V |
| `open_v2_25s` | `20260930-235056.569-open_fast_v2` | CCW | 25.2 s | 7.01 V |

The 14.7 s run in numbers: top speed 1.39 m/s, peak horizontal acceleration 0.56 g, control loop 99th percentile
32.0 ms, speed observer median error 0.01 m/s, stop at 1541 mm from the wall ahead inside the 1182–1957 mm start
window.

### Obstacle Challenge (start in the lot, 3 laps, 6 signs, parallel park; counter-clockwise; all 4 corners in the lot in every row)

| Program | Run ID | Time | Pack |
|---|---|---|---|
| **`obs_v17`** | `20261001-222840.106-obs_v17` | **55.8 s** | 8.25 V |
| `obs_v13` | `20261001-203331.245-obs_v13` | 57.6 s | 6.80 V |
| `obs_v4` | `20261001-171309.381-obs_v4` | 67.6 s | 7.17 V |
| `obs_v12` | `20261001-202156.652-obs_v12` | 68.2 s | 7.00 V |
| `obs_v3` | `20261001-165354.604-obs_v3` | 69.4 s | 7.45 V |
| `obs_v3` | `20261001-165946.260-obs_v3` | 71.2 s | 7.36 V |
| `obs_v5` | `20261001-173009.016-obs_v5` | 72.6 s | 6.99 V |
| `obs_v11` | `20261001-201055.680-obs_v11` | 73.3 s | 7.10 V |

Sign layout on the mat in these runs: 1.0 green, 1.2 red, 2.0 green, 2.2 red, 3.0 green, 3.2 green. On 2026-10-01,
8 of 18 Obstacle runs ended with a full park; the other 10 were development runs listed in
[Engineering decisions](04-engineering-decisions.md#version-history).

## Simulation results

SIM, calibrated plant `plant_mat1001`, one run each, all TRUSTED by the simulation queue.

| Program, direction | MAT | SIM on the mat's layout (4 × 1000 mm) | SIM on random corridors |
|---|---|---|---|
| `open_v2_25s` CW | blocked after 1 corner, 11.6 s | blocked after 1 corner, 9.2 s | blocked after 1 corner, 9.3 s (seed 1) |
| `open_v4` CCW | 28.6 s | 30.8 s, 0 contacts | 30.8 s (seed 5) |
| `open_v4` CW | 23.3 s / 26.3 s | 30.6 s, 0 contacts | 38.8 s (seed 1) |
| `BEST_OPEN` CCW | 18.7 s | 20.1 s, 0 contacts | 20.2 s (seed 5) |
| `BEST_OPEN` CW | not run on the mat (the CW 18.8 s run was `open_v5_18s`) | 18.2 s, 0 contacts | blocked at 31.1 s on 1000/600/600/600 (seed 1) |

`open_v7` with its `fast7` preset in the same simulator, seeds 1 to 6 in both directions on the mat's layout: 12 of 12 clean runs, 14.0–14.4 s (SIM); with the `l2` preset we race, 14.7 s counter-clockwise and 14.9 s clockwise (SIM). On random corridors it stayed clean, with 600 mm to 600 mm corners slower (up to 25 s, SIM). The last row matters for the event: in SIM `BEST_OPEN` blocked on narrow corridors, while `open_v7` stayed clean.

## Versioning

- Each program version is a separate file with one named change in its header. Proven versions are frozen: their
  SHA-256 is recorded and the file is never edited again; a faster version is a new file.
- Printed parts follow the same rule: a part that has been printed is never changed; a new version is a new file.
- The calibration file keeps the date and the test behind each measured number in its notes.
- Releases of this repository are tagged; the release notes name the programs and the body version of each tag.

## How to reproduce each number

| Number | Where it comes from | How to repeat it |
|---|---|---|
| 14.7 s Open | run `20261001-161301.412-open_v7` | `py -3 tools/bw.py run BEST_OPEN_14s` in the start section; the run log's `end` event |
| 55.8 s Obstacle with park | run `20261001-222840.106-obs_v17` | `py -3 tools/bw.py run obs_v17` with the car in the lot; the `end` event (reason `parked`, corners in 4) |
| Speed line 5.276 × (duty − 0.1012), rms 0.075 m/s | `profiles/plant_mat1001.json` | `py -3 tools/fit_plant.py --bias-from corners --no-save` over the run logs |
| Effective wheelbase 137–281 mm | same file, `wb_curve` | same fit; the 137 mm point from the turn-radius test at 0.2 m/s |
| Brake 2.08 m/s² | same file, `brake_decel` | same fit; stop test from 0.48 m/s for the ≥ 1.6 m/s² lower bound |
| Steering 30° left, 22° right, trim −4° | profile notes, program headers | servo sweep and turn-radius test; a straight run at each trim |
| Camera pitch 19.61° | run parameters of 2026-10-01 | `py -3 tools/bw.py preflight pitch` with a sign 500 mm ahead |
| Lidar 598–599 rpm, loop 99th percentile 32.0 ms | telemetry and `loop_stats` of the runs above | any run log |
| Size 224.8 × 111.0 × 157.2 mm | the BW-2 CAD model | measure the car (to be done before the event) |
| SIM tables | the simulator with `--mat1001` | `py -3 tools/sim_run.py open_v7 --profile wltoys_bw2 --mat1001 --open --corridors 1000,1000,1000,1000 --seed 5` |

<sub>[Back to the README](../README.md)</sub>

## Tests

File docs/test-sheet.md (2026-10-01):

# Test sheet

One row per run on the mat. Print it, fill it in by hand, and keep the sheets with the date. The run ID is the name
of the run's log file; the pack voltage is read with the car still before the run. The bench check in
[Build, test and reproduce](05-build-test-reproduce.md#bench-check-before-a-round) comes before the first run of a
session.

| Date | Run ID | Program and preset | Challenge | Direction | Corridors / signs drawn | Start (section or lot) | Pack V | Laps | Time (s) | Signs wrong side / touched | Park (full, partial, none) | One change from the last run | Notes |
|---|---|---|---|---|---|---|---|---|---|---|---|---|---|
| | | | | | | | | | | | | | |
| | | | | | | | | | | | | | |
| | | | | | | | | | | | | | |
| | | | | | | | | | | | | | |
| | | | | | | | | | | | | | |
| | | | | | | | | | | | | | |

<sub>[Back to the README](../README.md)</sub>

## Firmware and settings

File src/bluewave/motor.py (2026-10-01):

"""The WLtoys build's drive motor: one brushed 130 motor on a PWM + DIR driver (the team's Cytron MD13S) wired to the
Pi 5's GPIO.  The RRC Lite cannot run it: its firmware has no duty command, and its encoder speed PID ramps to 100 %
and never stops without an encoder (3d/bluewave_body/wl/research/electronics_wl.md 2.1).  The RRC Lite keeps the
steering servo, the IMU, the keys and the buzzer.

    SysfsPwm    hardware PWM through /sys/class/pwm.  The RP1 PWM0 chip is found by its DEVICE PATH (it is pwmchip2
                on kernel 6.6 and pwmchip0 on 6.12); channel 0 = GPIO12 (pin 32) with
                    dtoverlay=pwm-2chan,pin=12,func=4,pin2=13,func2=4        under [pi5] in /boot/firmware/config.txt
    LgpioPwm    lgpio's software PWM on the same pin: the fallback when the overlay or the sysfs permission is missing
    Pins        output pins through lgpio: the direction pin (MD13S DIR = GPIO16, pin 36), or two for an IN1/IN2 driver
    PwmMotor    a signed duty -> PWM + direction, with the safety rules of electronics_wl.md 2.3:
                  * duty 0 for `dir_dwell_ms` before the direction flips
                  * stop = BRAKE (MD13S: PWM low brakes, and DIR goes low after it so a PWM/DIR pair swapped at the
                    Grove joint still stops; a two-pin driver: both high) or COAST (two-pin: both low)
                  * a watchdog thread: duty 0 when nothing refreshed it for `watchdog_ms`
                  * a GUARDIAN process: a hardware PWM keeps running after its program dies, so a child process that
                    only reads a heartbeat pipe zeroes it when the pipe closes (crash, kill -9) or stays silent
                  * atexit, and `python -m bluewave.motor --off` for systemd's ExecStopPost
                  * an optional PLUG BRAKE (PlugBrake, armed by hw.Robot when params drive.brake.active = 1): a slow-
                    down to a lower speed the same way reverses the duty for a bounded time -- off by default
    PlugBrake   active braking toward a lower speed: reverse duty of bounded size and length, >= 50 ms at duty 0
                before each DIR flip, stopped by its own speed prediction or the lidar's
    open_motor  params drive.pwm -> a PwmMotor on the real hardware
    probe()     `python -m bluewave.motor --probe`: every pwmchip with its device path, which one matches, the gpiochips

Everything takes a sysfs `root` and an `lgpio` module, so the unit tests run on a fake tree and a fake lgpio.
"""
from __future__ import annotations

import atexit
import glob
import math
import os
import subprocess
import sys
import threading
import time

RP1_PWM0 = "1f00098000.pwm"          # [3RD, verify with --probe] RP1 PWM0; 1f0009c000.pwm (PWM1) drives the fan
ROOT = os.path.dirname(os.path.dirname(os.path.abspath(__file__)))


# ---------------------------------------------------------------------------------------------------------- sysfs
def _write(path: str, value) -> None:
    with open(path, "w") as f:
        f.write(str(value))


def _read(path: str, default: str = "") -> str:
    try:
        with open(path) as f:
            return f.read().strip()
    except OSError:
        return default


def find_chip(root: str = "/sys", match: str = RP1_PWM0):
    """The pwmchip directory whose device path contains `match`, or None.  /sys/class/pwm/pwmchipN are symlinks into
    /sys/devices/.../<match>/pwm/pwmchipN; the number changes between kernels, the device path does not."""
    for c in sorted(glob.glob(os.path.join(root, "class", "pwm", "pwmchip*"))):
        if match in os.path.realpath(c).replace("\\", "/"):
            return c
    for depth in range(1, 4):                       # platform/axi/1000120000.pcie/1f00098000.pwm on the Pi 5
        pat = os.path.join(root, "devices", "platform", *(["*"] * depth), match, "pwm", "pwmchip*")
        hits = sorted(glob.glob(pat))
        if hits:
            return hits[0]
    return None


class SysfsPwm:
    def __init__(self, chip_dir: str, channel: int = 0, freq_hz: float = 490.0, wait_s: float = 1.5):
        self.chip, self.ch = chip_dir, int(channel)
        self.dir = os.path.join(chip_dir, "pwm%d" % self.ch)
        if not os.path.isdir(self.dir):
            _write(os.path.join(chip_dir, "export"), self.ch)
        duty = os.path.join(self.dir, "duty_cycle")
        end = time.monotonic() + wait_s              # udev sets the group a moment after the export
        while not (os.path.isfile(duty) and os.access(duty, os.W_OK)):
            if time.monotonic() > end:
                raise OSError("%s did not become writable (the user in group gpio? the udev rule?)" % duty)
            time.sleep(0.02)
        self.period = int(round(1e9 / float(freq_hz)))
        self._w("duty_cycle", 0)                     # before the period: a period below the old duty is refused
        self._w("period", self.period)
        self._w("duty_cycle", 0)
        try:
            self._w("polarity", "normal")            # only writable while disabled; an enabled channel keeps its own
        except OSError:
            pass
        self._w("enable", 1)
        self.how = "sysfs %s ch%d %.0f Hz" % (os.path.basename(chip_dir), self.ch, 1e9 / self.period)

    def _w(self, name: str, value):
        _write(os.path.join(self.dir, name), value)

    def set(self, duty: float):
        """0..1.  Written every call (no cache): the guardian may have zeroed it behind our back."""
        self._w("duty_cycle", int(round(self.period * min(1.0, max(0.0, float(duty))))))

    def off(self):
        self.set(0.0)

    def close(self):
        self.off()                                   # stays ENABLED at 0 %: the pin is driven low = MD13S brake


# ---------------------------------------------------------------------------------------------------------- lgpio
def open_chip(lg, label: str = "rp1"):
    """An lgpio handle on the gpiochip whose name or label contains `label` (the Pi 5's RP1 is gpiochip4 on kernel 6.6,
    gpiochip0 on 6.12), or chip 0 when none matches."""
    first = None
    for n in range(8):
        try:
            h = lg.gpiochip_open(n)
        except Exception:
            continue
        try:
            info = lg.gpio_get_chip_info(h)
            text = " ".join(str(x) for x in info[2:4]).lower()
        except Exception:
            text = ""
        if label and label.lower() in text:
            if first is not None:
                lg.gpiochip_close(first)
            return h
        if first is None:
            first = h
        else:
            lg.gpiochip_close(h)
    if first is None:
        raise OSError("no gpiochip could be opened")
    return first


class LgpioPwm:
    def __init__(self, lg, handle, gpio: int, freq_hz: float = 490.0):
        self.lg, self.h, self.gpio, self.freq = lg, handle, int(gpio), float(freq_hz)
        lg.gpio_claim_output(handle, self.gpio, 0)
        self.how = "lgpio software PWM on GPIO%d %.0f Hz" % (self.gpio, self.freq)

    def set(self, duty: float):
        self.lg.tx_pwm(self.h, self.gpio, self.freq, 100.0 * min(1.0, max(0.0, float(duty))))

    def off(self):
        self.lg.tx_pwm(self.h, self.gpio, self.freq, 0.0)
        self.lg.gpio_write(self.h, self.gpio, 0)

    def close(self):
        self.off()


class Pins:
    def __init__(self, lg, handle, pins):
        self.lg, self.h, self.pins = lg, handle, [int(p) for p in pins]
        for p in self.pins:
            lg.gpio_claim_output(handle, p, 0)
        self.levels = [0] * len(self.pins)

    def write(self, levels):
        for p, v in zip(self.pins, levels):
            self.lg.gpio_write(self.h, p, int(v))
        self.levels = [int(v) for v in levels]

    def close(self):
        self.write([0] * len(self.pins))


# ---------------------------------------------------------------------------------------------------------- guardian
class Guardian:
    """The child process that stops the motor when this process can no longer: its stdin is a heartbeat pipe."""

    def __init__(self, args: list):
        env = dict(os.environ, PYTHONPATH=ROOT + os.pathsep + os.environ.get("PYTHONPATH", ""))
        self.p = subprocess.Popen([sys.executable, "-m", "bluewave.motor", "--guard"] + [str(a) for a in args],
                                  stdin=subprocess.PIPE, cwd=ROOT, env=env)
        self.ok = True

    def beat(self):
        if not self.ok:
            return
        try:
            self.p.stdin.write(b".")
            self.p.stdin.flush()
        except (OSError, ValueError):
            self.ok = False                          # the guardian is gone: the watchdog thread still guards

    def close(self):
        try:
            self.p.stdin.close()
            self.p.wait(1.5)
        except Exception:
            pass


def guard_main(argv) -> int:
    """`--guard --pwm-dir DIR | --lgpio-label L --gpio G  [--dir-pins 16,..] [--silence-ms 800]`: zero the motor when the
    heartbeat pipe closes (the parent died) or stays silent for silence-ms (the parent hung)."""
    a = dict(zip(argv[::2], argv[1::2]))
    silence = float(a.get("--silence-ms", 800)) / 1000.0
    state = dict(t=time.monotonic(), eof=False)

    def on_term(_sig, _frm):
        # systemd stops the whole cgroup at once (KillMode=control-group): the guardian gets SIGTERM together with the
        # agent, and without a handler it exited WITHOUT zeroing -- a hung agent's PWM then ran on
        _zero(a)
        raise SystemExit(0)

    try:
        import signal
        signal.signal(signal.SIGTERM, on_term)
    except (ImportError, ValueError, OSError):
        pass

    def reader():
        while True:
            b = sys.stdin.buffer.read(1)
            if not b:
                state["eof"] = True
                return
            state["t"] = time.monotonic()

    threading.Thread(target=reader, daemon=True).start()
    zeroed = False
    while True:
        time.sleep(0.02)
        quiet = time.monotonic() - state["t"] > silence
        if state["eof"] or (quiet and not zeroed):
            _zero(a)
            zeroed = True
            if state["eof"]:
                return 0
        elif not quiet:
            zeroed = False


def _claim_low(label: str, pins: list) -> int:
    """Claim `pins` as outputs driven low through lgpio; returns how many were claimed.  A pin the parent still holds
    refuses the claim (the parent is alive and hung): skipped, the next call tries again.  lgpio's claims die with the
    process that made them, so the pins stay claimed only while this one lives."""
    try:
        import lgpio
        h = open_chip(lgpio, label)
    except Exception:
        return 0
    n = 0
    for p in pins:
        try:
            lgpio.gpio_claim_output(h, p, 0)
            n += 1
        except Exception:
            pass
    if not n:
        try:
            lgpio.gpiochip_close(h)                  # nothing claimed: do not leak a handle on every quiet spell
        except Exception:
            pass
    return n


def _zero(a: dict):
    dirs = [int(p) for p in str(a.get("--dir-pins", "")).split(",") if p.strip()]
    label = a.get("--lgpio-label", "rp1")
    if a.get("--pwm-dir"):
        try:
            _write(os.path.join(a["--pwm-dir"], "duty_cycle"), 0)
        except OSError:
            pass
        if dirs:
            _claim_low(label, dirs)                  # the DIR pin low too (see PwmMotor._stop: a swapped PWM/DIR joint)
    elif a.get("--gpio"):                            # lgpio: the parent's claim is released when it dies
        _claim_low(label, [int(a["--gpio"])] + dirs)


# ---------------------------------------------------------------------------------------------------------- plug brake
PLUG_DWELL_MIN_S = 0.050    # [3RD MD13S] duty 0 at least this long before a DIR flip.  The plug brake holds it on its
#                             own, whatever drive.pwm.dir_dwell_ms says (a floor under the scale of a safety action)


class PlugBrake:
    """Active braking toward a LOWER speed in the SAME direction (params drive.brake; hw.Robot arms it).

    The mechanism: on the MD13S (sign-magnitude) duty 0 = PWM low = the motor shorted, which slows the car on the
    motor's own time constant -- dv/dt = -v / tau, tau 0.52 s measured from 0.25 m/s [MAT 2026-09-30].  From 1.7 m/s
    that is 0.9 m of travel to stop and 0.3 m to lose 0.5 m/s.  A REVERSE duty d drives toward the reverse speed of that
    duty instead: dv/dt = -(v + v_ss(d)) / tau, a stronger pull the whole way.

      pre    duty 0 (the motor's own brake) for >= PLUG_DWELL_MIN_S: the MD13S must never see DIR flip under duty
      plug   reverse duty = the largest that keeps the predicted deceleration <= ax_max (the grip / nose-over limit over
             a safety factor), capped at `duty` and the driver's max; at most max_ms long.  Ends when the speed --
             its own prediction, or the lidar's when that is fresh and lower -- reaches the target (plus the margin the
             post phase still takes off), or falls to v_floor (a plug near rest would reverse the car)
      post   duty 0 again for >= PLUG_DWELL_MIN_S before the caller's forward duty comes back

    It never runs through a stop: a zero duty (stop, E-STOP, the dead-man, the stall cut), a reversal, or the watchdog
    end it at once (PwmMotor), so every safety path stays the plain PWM-low brake the mat measured.  The deceleration
    at a reverse duty is [EST] (the plant law above with the mat's brake tau); the mat test is in the profile's notes.
    """

    def __init__(self, v0: float, target: float, cfg: dict, line: dict, meas=None, now: float | None = None):
        now = time.monotonic() if now is None else now
        self.sign = 1.0 if v0 >= 0.0 else -1.0
        self.v = abs(float(v0))                     # the predicted speed along the run direction, m/s
        self.target = abs(float(target))
        c = cfg or {}
        self.duty_cap = max(0.0, min(float(c.get("duty", 0.30)), float(line.get("max_duty", 0.5))))
        self.max_s = max(0.0, float(c.get("max_ms", 250))) / 1000.0
        self.dwell = max(PLUG_DWELL_MIN_S, float(line.get("dwell_ms", 50) or 0.0) / 1000.0)
        self.margin = max(0.0, float(c.get("v_margin", 0.05)))
        self.v_floor = max(0.10, float(c.get("v_floor", 0.25)))          # a floor: never plug a car near rest
        self.ax_max = max(0.0, float(c.get("ax_max", 3.0)))
        self.tau = max(0.05, float(c.get("tau_s", 0.52)))
        self.intercept, self.slope = float(line["deadband"]), max(1e-3, float(line["mps_per_duty"]))
        self.comp = float(line.get("comp", 1.0) or 1.0)
        self.meas = meas                            # () -> signed m/s (the lidar's, fresh) or None
        self.t0 = self.t_last = self.t_phase = now
        self.phase, self.t_plug, self.why = "pre", None, ""
        self.peak = 0.0                             # the largest reverse duty it asked for
        self.v_start = self.v

    def retarget(self, target: float):
        self.target = min(self.target, abs(float(target))) if self.phase != "post" else self.target

    def release(self, why: str = "released", now: float | None = None):
        """End the plug now but keep the post phase: >= PLUG_DWELL_MIN_S at duty 0 before the forward duty returns."""
        if self.phase != "post":
            self.why, self.phase = self.why or why, "post"
            self.t_phase = time.monotonic() if now is None else now

    def v_stop(self) -> float:
        """The speed to end the plug at: the post phase's PWM-low dwell still takes v x (1 - e^(-dwell/tau)) off."""
        return (self.target + self.margin) * math.exp(self.dwell / self.tau)

    def law(self, v: float) -> float:
        """The reverse duty (> 0, at the pin) whose predicted deceleration (v + v_ss(d)) / tau is ax_max at speed v,
        capped; 0 = the motor's own brake is already at ax_max (or a reverse duty under the intercept adds nothing)."""
        x = self.ax_max * self.tau - v
        if x <= 0.0:
            return 0.0
        d = min(self.duty_cap, (self.intercept + x / self.slope) * self.comp)
        return d if d > self.intercept * self.comp else 0.0

    def _vss(self, duty_along: float) -> float:
        """The steady speed along the run direction for a duty at the pin (negative = the reverse pull)."""
        a = abs(duty_along) / self.comp
        if a <= self.intercept:
            return 0.0
        return math.copysign((a - self.intercept) * self.slope, duty_along)

    def step(self, now: float, applied: float):
        """The duty for now (signed, at the pin), or None when the brake is over.  `applied` = the signed duty the
        driver had since the last call: the prediction integrates it."""
        dt = max(0.0, now - self.t_last)
        self.t_last = now
        self.v = max(0.0, self.v + (self._vss(applied * self.sign) - self.v) * min(1.0, dt / self.tau))
        if now - self.t0 > 2.0 * self.dwell + self.max_s + 0.1:
            self.why = self.why or "deadline"
            return None
        if self.phase == "pre":
            if now - self.t_phase < self.dwell:
                return 0.0
            self.phase, self.t_phase = "plug", now
        if self.phase == "plug":
            m = None
            if self.meas is not None:
                try:
                    m = self.meas()
                except Exception:
                    m = None
            v_seen = self.v if m is None or m != m else min(self.v, max(0.0, float(m) * self.sign))
            end = ("target" if v_seen <= self.v_stop() else "v_floor" if v_seen <= self.v_floor else
                   "max_ms" if self.t_plug is not None and now - self.t_plug >= self.max_s else "")
            if not end:
                d = self.law(v_seen)
                if d > 0.0 and applied * self.sign < 0.0 and self.t_plug is None:
                    self.t_plug = now                # the driver is reversed now: max_ms counts from here
                self.peak = max(self.peak, d)
                return -self.sign * d if d > 0.0 else 0.0
            self.why, self.phase, self.t_phase = end, "post", now
        if now - self.t_phase < self.dwell:
            return 0.0
        return None

    def summary(self) -> dict:
        return dict(v_start=round(self.v_start, 3), target=round(self.target, 3), v_pred=round(self.v, 3),
                    why=self.why, peak_duty=round(self.peak, 3), secs=round(self.t_last - self.t0, 3))
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

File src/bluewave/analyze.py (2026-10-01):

"""The crash / near-miss analyzer (BRAIN4_SPEC 6): one run file (+ its recording) -> WHERE and WHY the car touched
something, as runs/<id>.report.json and a standalone runs/<id>.report.html.

    python -m bluewave.analyze RUN.jsonl [--rec DIR|auto|none] [--out-dir DIR] [--no-html] [--json-progress]
                                         [--set an.near_mm=20 ...] [--truth]

Exit 0; 2 = the run file cannot be read; 3 = an internal error (a minimal report with "error" is still written).
It never imports hw and never opens a device: the agent runs it as a separate niced process after a run
(bluewave/runs_api.py), the laptop runs it on pulled or simulated runs (tools/bw_analyze.py).

The mechanism, in the order it runs:
  1. read the run file (meta, log, tel 20 Hz, live 5 Hz, clock, imu 50 Hz) and the recording (steps.jsonl 40 Hz pose
     + command + state, JPEG frames, lidar scans); tie the recording's monotonic clock to the run file's Unix time
     (the `clock` record, the recording header, else start.t - first step - 0.05 s: "estimated +-0.1 s");
  2. per frame (160 x 120 decode): the wall bases of vision.edges, "near wall" (>= 60 % of the central half of the
     columns clipped WALL: a wall inside the band the camera cannot see, 213 mm ahead of the A1's nose), "lens
     blocked" (below the horizon >= 95 % dark and <= 5 % of the columns with a seen base, for >= 0.5 s -- measured on
     the M4 frames 151-1467: 99-100 % dark below the horizon, 0-4 seen columns; the room above the wall keeps the
     WHOLE image at 66 % dark, so the whole-image 80 % of the first draft never fires), and the 80 x 60 grey
     thumbnail difference (still 0.44, driving 8-12 on the mat recording: the A1's speed sensor);
  3. per lidar scan (lidar.loc = 1 only: the stock LD19 scans above the walls): the body clearance of the nearest
     return, the car's own returns (bins near the body in > 50 % of the scans) left out;
  4. the detectors D1-D13 of 6.3 -> candidates; fused into incidents (6.3 Fusion); each incident gets WHERE (pose,
     section, the map object and the part of the car, 6.4), WHAT the program was doing (the decision), WHY (the first
     of 12 attribution rules that holds, 6.5) and a fix hint;
  5. the report JSON (schema bw.report/1, 6.7) with a 10 Hz timeline, and the HTML (bluewave/report_html.py).

Thresholds are the an.* params (DEFAULTS below; the run's robot_params an.* override them, then --set):
[MAT 2026-09-23] contacts read 0.54-1.08 g in tel's 3-D deviation, a clean lap's max 0.33 g, a lone 0.62 g spike
with nothing near (M4 6.72 s) is NOT a contact -- a spike needs corroboration.
[MAT 2026-09-30] the WLtoys' own stick-slip start and brake jolt the IMU ~0.5 g: inside the command's start / brake
window and under an.jolt_g (from the body profile) a spike is the drive, not a contact (D1, stats.jolts).
"""
from __future__ import annotations

import argparse
import json
import math
import os
import sys
import time
import traceback

import numpy as np

from . import blackbox as BB
from . import field as F

VERSION = 1
SCHEMA = "bw.report/1"

DEFAULTS = {                    # the an.* keys of BRAIN4_SPEC 2.1 (without the prefix)
    "auto": 1,                  # the agent analyses every run when it ends
    "acc_contact_g": 0.45,      # [MAT 2026-09-23 M4-M6] 3-D deviation of a contact (tel 20 Hz); [DAY1] re-check at 50 Hz
    "acc_bump_g": 0.28,         # a "bump?" candidate (weak)
    "gyro_jerk_dps": 60.0,      # yaw-rate residual jump within 0.1 s
    "push_s": 0.6,              # commanded >= 0.08 m/s this long while the measured motion < ratio x command
    "push_ratio": 0.2,
    "touch_mm": 8.0,            # lidar body clearance of a contact
    "near_mm": 30.0,            # footprint clearance of a near miss
    "merge_s": 0.6,             # candidates this close in time are one incident
    "loop_gap_ms": 150.0,       # a control step gap this long (while driving) is an overrun
    "pose_jump_mm": 80.0,       # a relocalisation that moves the pose this far marks the pose before it as wrong
    "sxy_bad_mm": 60.0,
    "bat_rest_v": 7.5, "bat_min_v": 7.0, "bat_sag_v": 0.5,
    "thumbs": 3,                # frames per incident (at t, t - 0.5 s, t - 1.0 s)
    "max_incidents": 40,
    "cam_frames": 1,            # analyse the recorded frames (the A1's camera signals, D6)
    "why_truth": 0,             # 1 = the simulator's truth (tel.sim) may decide WHERE / WHY too.  0 (always, for any
    #                             report the team reads): the truth only SCORES the detectors (D13, the report's
    #                             `truth` / `detector` blocks) -- the causes are what the mat, which has no truth, would
    #                             get (review 2026-09-25: with the truth the M4-type push read LOC_POSE_OFF, without it
    #                             UNKNOWN_OBSTACLE / TURN_RADIUS, and "the analyzer names the cause" was graded on it)
    # the drive's OWN jolts (D1): the WLtoys' stick-slip start and its shorted-motor brake shake the IMU ~0.5 g
    # [MAT 2026-09-30] -- over acc_contact_g, and one or two samples long like a hit, so every start from rest read
    # "contact".  A spike inside a jolt window of the command timeline and under jolt_g is the drive, not a contact,
    # unless something independent of the spike says contact (a near obstacle, a push, a stall).
    "jolt_g": 0.0,              # the ceiling: 0 = from the body -- a gpio_pwm drive (the WLtoys) JOLT_X x its measured
    #                             start jolt (the run's mock.plant.start_jolt_g, else its profile file's, else
    #                             acc_contact_g); the stock A1's encoder drive: none (off)
    "jolt_start_s": 0.3,        # a start from rest (or a reversal): the 60 ms kick breaks it loose at once -- [SIM
    #                             2026-09-29, the WLtoys plant with its 0.5 g start jolt] every jolt came 0.00-0.03 s
    #                             after the command (the 20 Hz tel's jitter is inside 0.3 s)
    "jolt_brake_s": 0.3,        # a brake (to rest, a reversal, a cut to <= half): the shorted motor bites at once
    "jolt_block_s": 1.5,        # ...but a car braking as it COASTS into a wall hits inside that window too: [SIM
    #                             2026-09-29, lapstop with the mirrored lidar] 8 of 9 true contacts came 0.02-0.26 s
    #                             after a brake command, each followed 1.2 s later by the program's turn_blocked.  A
    #                             program's blocked / stuck event (PUSH_EVENTS) this long after a spike = a contact
    "cam_stale_ms": 600.0,      # tel.cam_age_ms above this while driving: the camera stopped (D11b).  The robot's
    #                             age is 0-70 ms at 15-30 fps; the simulator stamps a frame before rendering it, so its
    #                             age reads 120-480 ms on a loaded machine -- 600 keeps that out, a frozen grabber grows
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

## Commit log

2026-06-01 Initial commit — Blue Wave Team WRO Future Engineers 2026 - Professional README with team branding - Open Challenge: PD wall-following controller (KP=0.1, KD=0.09) - Obstacle Challenge: PD + Pixy2 vi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
2026-06-01 Add wiring schematic diagram (Fritzing)
2026-06-04 Update challenge firmware and align docs with the real robot
    - Replace Open & Obstacle sketches with the tested unified controller
    (PID wall-follow + front-ultrasonic avoidance + BNO055 lap counting + Pixy2)
    - Fix README tuned-parameter table, wiring and sensor list to match the code
    (3x HC-SR04, BNO055 IMU, servo on D10, Green=140 / Red=40)
    - Add the 3D main-body model file to Models/
    - Add a Meet "Tracer" section
    [WRO_AUMers_main_body_3D_Design_v2.3mf]
2026-06-04 Fix folder pages: videos gallery, 3D model file, schematic wiring
2026-06-04 Replace 3D model image with labeled Tracer exploded view
2026-06-04 Redesign README: new layout, narrative voice, mermaid control-flow
2026-09-15 Rewrite the README for the orange car and the Asia final
    The old README described the red Tracer design, the June sketch and the
    previous team. It now documents the orange car that competes: mobility,
    power and sensing with the 40-degree sonar geometry, the open_v20 and
    obstacle_v20 strategies including the front-wall park, the module map,
    build and upload steps with library versions and the PRACTICE switch,
    real-car and simulator results kept apart, the engineering log, and the
    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
2026-09-15 Update the photo, video and wiring pages for the orange car
    Vehicle_Photos lists the six views and the team photo the rules require,
    with the exact file names to commit. The June attachment links are kept
    as plain links until the team checks which car they show.
    videos records the length and driving time of the two June clips and
    the two videos still needed on the finals code.
    Schemes gives the finals pin map including the A2 start switch, lists
    what the June Fritzing diagram is missing, and marks the power path as
    unconfirmed.
2026-09-15 Mark the red body model as a design study, not the competing car
    Models/README.md now says plainly that the red body files are not the
    orange car, lists the objects in the .3mf project, and replaces the old
    print settings with the ones actually stored in the file. The model
    files themselves are unchanged.
2026-09-15 Correct facts in the README and the red body page
    - The 6 September build had a timed park; it never reached it (fix 26).
    - The simulator varies speed by 12 %; the 1.3-2.2 battery ratio is a spec-file assumption.
    - Fix 4 in obstacle_kuwait brought the avoid PWM 25 and the stiction kick; v20 keeps both.
    - The nearest-pillar range came from obstacle_kuwait, not v20.
    - open_v20 also adds the A2 start wait; PWM 38 ends at a 150 cm front reading.
    - Name open_kuwait and obstacle_kuwait instead of asserting which code ran at the national round.
    - Drive axle and four illustration labels marked as unverified.
    - The red body files are dated 2025-11-20, so they are not a future design study.
2026-09-15 Fix README wording and add missing rubric items to the TODO list
    - Header line now says 1st place at the Kuwait national round and names the
    Asia final as the next event, so it no longer reads as an Asia final win.
    - Replace the quoted "excellent" lot-exit rating with what the notes support:
    the exit worked, judged by eye, with no attempt count.
    - Replace the slogan-style closing line in 9.3 with a plain next step.
    - Section 3.4 said gear ratio and mechanical changes were in the checklist;
    add them, with the motor part number and servo model.
    - Give Appendix C.2's engineering journal a place in section 1 and the
    checklist, and add the rule 7 link-submission and 12-month public items.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
2026-09-15 Put the finals sketches in src
    Open_Challenge.ino and Obstacle_Challenge.ino are now open_v20 and obstacle_v20 with PRACTICE 0, so the car waits for the A2 start switch (rule 9.11). src/README.md maps every function to its pins an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
2026-09-15 Rename the body model
    Models/README.md now lists the five parts and the print settings saved in the project. The old exploded view with wrong labels is removed.
    [BlueWave_main_body_v2.3mf]
2026-09-15 Add wiring and sensor diagrams
    System overview, sensor layout, wiring pin map and power tree as SVG, with the unconfirmed supply paths drawn dashed.
2026-09-15 Split the documentation into criterion pages
    A short front README plus one page per Appendix C criterion in docs/. Flash sizes now say how the Pixy2 library must be set up. Photo, video and wiring pages point to the new diagrams.
2026-09-15 Add system, sensor and pin map diagrams
2026-09-15 Add part choices, the 64-point result and tighten every page
2026-09-15 Move the front sonar trigger to A0 and correct the sketch header comments
    D13 is the Pixy2 SPI clock on the ICSP header, so the front trigger goes to A0. Line numbers are unchanged; rule references now point to 9.11 for the start switch.
2026-09-15 Document the two-battery supply, the A0 front trigger and the 61-point result
    Power tree and system overview for two batteries, datasheet figures in the current budget, a blank test sheet, the engineering journal PDF, the parts photo without the old body, and the pin map and d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
2026-09-15 Add the full wiring schematic with its source and archive the June drawing
    One sheet with every signal, supply and ground wire, an editable SVG source, a ground table, and the June 2026 Fritzing PDF moved to Schemes/archive_june_2026.
2026-09-15 Refresh the exploded view and restyle the diagram sheets
    Exploded view with corrected part labels (284131 chassis, I2C, 4WD drive train, battery lead); all diagrams on the engineering-sheet frame used by the wiring schematic; new dimension sheet from the side and front photos.
2026-09-15 Add dimensions, mass budget, torque estimate and full power budget
    Chassis identified as WLtoys 284131 (4WD propshaft, 130 motor, 17:29 first stage). Height, wheelbase, track and wheel size from photos scaled to the measured 200 x 125 mm; mass budget about 360 g; mo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
2026-09-15 Race Obstacle build in src, front trigger on D13, and both challenge videos
    src/Obstacle_Challenge is the mat-tested build (obstacle_kuwait with fixes 1-12); the v20 development build stays at tag v2.0-asia-final and the design pages link there. Front trigger documented on D13 across pages, diagrams and the schematic. Video cards and links for the Open and Obstacle videos on the front page.
2026-10-01 Replace the Arduino sketches with the Raspberry Pi 5 code
    The car now runs on a Raspberry Pi 5 with the RRC Lite board, an LD19 lidar
    and an HP60C camera. src/ holds the robot package, the race programs
    (BEST_OPEN_14s for Open, obs_v17 for Obstacle), the calibration profiles,
    the OS setup scripts, the race-mode launcher and the laptop tools.
    [agent.py, analyze.py, blackbox.py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]
2026-10-01 Models, wiring and photo pages for the BW-2 car
    Models: the five BW-2 parts printed for the car, byte-identical to the
    printed files. Schemes: new wiring schematic from the calibration file.
    Vehicle_Photos: old car photos removed; the six views of the new car will
    be added when they are taken.
    [01_D1_deck_darkgrey.stl, 02_L1_frame_battery_tray_darkgrey.stl, 04_tower_blue.stl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]
2026-10-01 Diagrams and images for the WLtoys car
    System overview, pin map, power tree, sensor layout and dimensions redrawn
    for the new car; Open run speed trace and effective wheelbase plotted from
    the run log and the plant file; CAD renders of the BW-2 body; old car
    images removed.
2026-10-01 Remove the engineering journal of the old car
    The journal described the Arduino car. The criterion pages in docs/ now
    cover the current car; the old journal stays in the history.
2026-10-01 Rewrite the documentation for the WLtoys car
    README and the five criterion pages now describe the current car, its mat
    results and the next event (WRO 2026 Open Championship Europe, Zagreb).
    Arena page gains the obs_v17 replay. Test sheet and video page updated.
